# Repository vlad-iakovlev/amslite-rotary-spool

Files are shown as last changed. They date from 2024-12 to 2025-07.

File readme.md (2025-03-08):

# AMSLite Rotary Spool Holder

This project provides 3D printable rotary spool holder models, including two versions: **Bambu Style** and **Universal Version**. The rotary spool holder helps maintain filament tension during printing, reducing the likelihood of tangling and lowering the risk of print failures.

## **Features and Benefits**

1. **Easy to Print & Print Optimized**  
   The design has been optimized to reduce the need for support structures and enhance Z-axis strength. By changing the print direction, you can achieve better strength.

2. **Low Cost**  
   The universal version uses only 59g of filament, and the version with secondary claws uses only 92g of filament. The hardware costs less than 1 RMB, making it very cost-effective.

3. **Wide Filament Reel Compatibility**  
   - **Secondary Claw System**: The design includes a flexible secondary claw system that can adapt to different filament reel hole diameters, improving stability and reducing the risk of tangling. The secondary claws can be removed from the shell and assembled onto the main claws, supporting larger reels, especially those with larger hole diameters (e.g., Jayo, Sunlu brands). This modular system ensures higher stability and minimizes the chances of tangling, making it suitable for filament reels with various core diameters.
   - **Universal Version**: The design keeps the bolt diameter as small as possible (the bolt area diameter is only 40.69mm), allowing for compatibility with smaller reels, such as Sunlu 250g filament reels. The original AMSLite cannot accommodate such reels, but the universal version can. The universal version has broader compatibility, uses fewer materials, and prints faster. While it requires screwing the nut for filament reel change, it won't suffer from plastic fatigue like the elastic claw version and won't have the dropping issue that the original version may have when locking the reel in place.

4. **Replaceable Parts**  
   Except for the claw components, all other parts of the Bambu style version are replaceable as spare parts in case the original version gets damaged.

## **Required Hardware**

The rotary spool holder requires two hardware components to function properly:

1. **Torsion Spring**  
   - **Wire Diameter**: 0.8mm  
   - **Outer Diameter**: 9mm  
   - **Number of Turns**: 5  
   - **Rotation Direction**: 180° Left or Right  
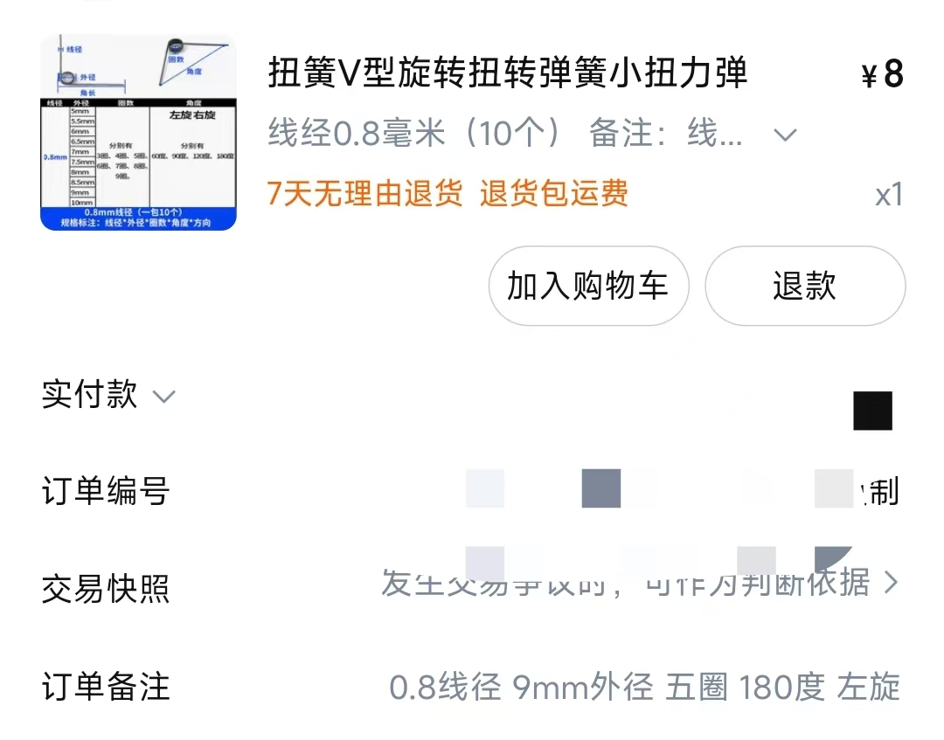
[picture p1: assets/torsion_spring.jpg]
Torsion Spring
   - 

2. **Three-Wave Gasket**  
   - **For Universal Version**  
     - **Dimensions**: 25mm x 31mm x 0.4mm  
     - **Height**: 2.9mm  
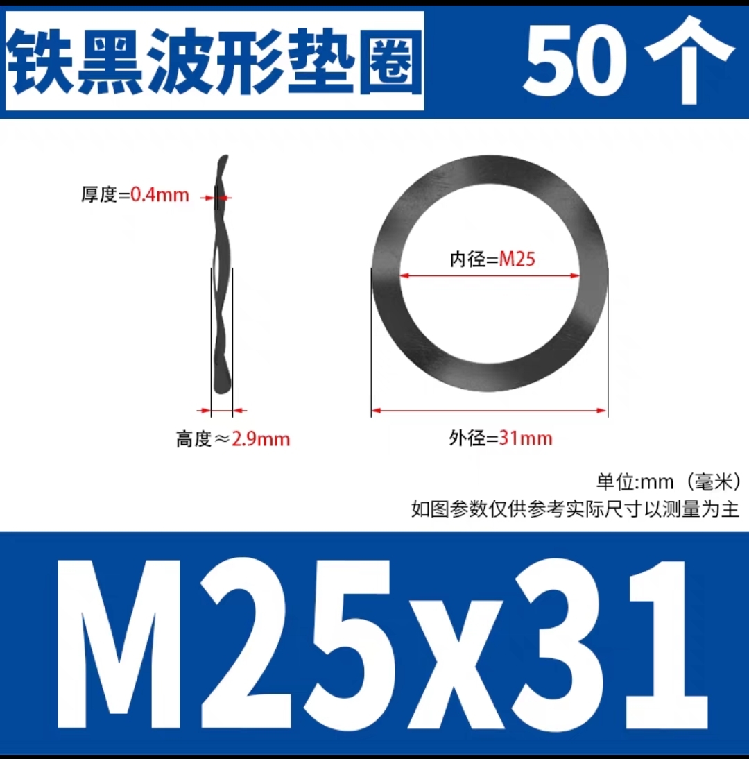
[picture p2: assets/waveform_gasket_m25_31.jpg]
Three-Wave Gasket
     - 
   - **For Bambu Style Version**  
     - **Dimensions**: 27mm x 34mm x 0.4mm  
     - **Height**: 3.1mm  
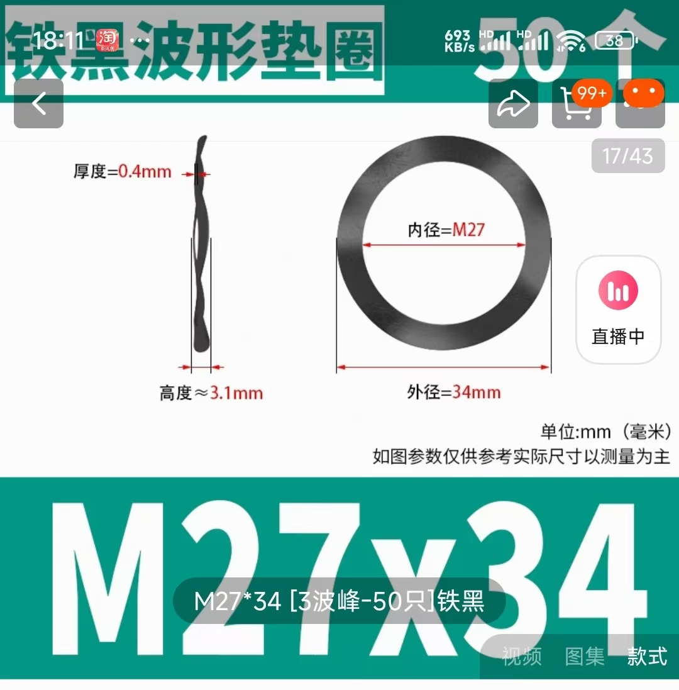
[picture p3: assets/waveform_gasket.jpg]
Three-Wave Gasket
     - 

## **Project Folder Structure**

- **assets/**: Contains snapshots, real photos, and images of hardware components.
- **3mf/**: Contains 3MF files optimized for easy printing.
- **docs/**: Usage instructions.
- **stls/**: Contains 3D model files.
  - **xxx.stl**: Integrated model.
  - **xxx_pieces/**: Split model components for easier printing.

## **3MF Files**

To simplify the printing process, 3MF files are provided. The necessary model files, orientations, and support settings have been preconfigured in the 3MF files. These files have been tested, and you can directly use them in **Orca** or **Bambu Studio**.

### [Bambu Style](./docs/bambu-style.md)
- **all-in-one.3mf**: 3MF file for the rotary spool holder (with secondary claws), all parts are placed on one plate, including both green and yellow core options (select one).
- **amslite-rotary-spool-with-secondary-claws.3mf**: 3MF file for the rotary spool holder (with secondary claws), with parts distributed across three plates. The first plate includes the base, shell, main claw seat, and main claws; the second plate includes the shaft, shaft cover, core (green and yellow, choose one), and a 1.2mm gasket; the third plate includes the secondary claw seat and secondary claws.
- **others**: Five plates: the first plate includes all 10 sizes of gaskets, the second plate includes the torsion spring bending template (including both left and right versions), the third plate includes an all-in-one main claw seat, the fourth plate includes an all-in-one core (including both yellow and green), and the fifth plate includes an all-in-one shaft.

### [Universal Version](./docs/universal-version.md)
- **universal-amslite-rotary-spool-holder-with-auto-rewind**: 3MF file for the universal rotary spool holder, including all required model files (base, shell, shaft, shaft cover, core, 1.2mm gasket, and reel nut).
- **universal-others**: Four plates: the first plate includes all 10 sizes of gaskets, the second plate includes the torsion spring bending template (including both left and right versions), the third plate includes an all-in-one core (including both yellow and green), and the fourth plate includes an all-in-one shaft.

### Other Files
- **torsion-spring-bending-template.3mf**: Includes the torsion spring bending template. The first plate is for left-hand springs, and the second plate is for right-hand springs.
- **amslite-spool-holder-cap-with-number.3mf**: Includes four numbered shaft caps (1, 2, 3, 4), useful for labeling filament reels.
- **ams-riser-v2-ams-lite-rotary-holder.3mf**: A rotary spool holder mount compatible with AMS Riser v2.
- **ams-riser-v2-ams-lite-rotary-holder-withAMS.3mf**: A rotary spool holder mount compatible with AMS Riser v2, printed separately with different colors for the yellow and green slots.
- **debug-xxx.3mf**: Includes a hollowed-out cover and four different gasket sizes for debugging. Refer to the [debug-guide](./docs/debug-guide.md) for related documentation.

## **License**

This project is licensed under the [Creative Commons Attribution 4.0 International License](https://creativecommons.org/licenses/by/4.0/), feel free to modify and distribute with proper attribution.

## **Disclaimer**

Please note that the rotary spool holder and secondary claw system design is not intended for high-load applications or professional tool use. It is suitable for everyday 3D printing filament management.

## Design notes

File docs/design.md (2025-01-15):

# AMS Lite Rotary Spool Design Document

This document provides a detailed overview of the design process for the AMS Lite Rotary Spool, including the creation and assembly steps of each component to ensure optimal functionality and performance.

## Table of Contents

- [Introduction](#Introduction)
- [Design Process](#Design-Process)
- [Design Challenges and Solutions](#Design-Challenges-and-Solutions)
- [Conclusion](#Conclusion)

## Introduction

The AMS Lite Rotary Spool is a versatile spool designed to meet the needs of 3D printing applications. It supports various types and sizes of filaments while ensuring ease of printing and low production cost.

## Design Process

The design of the Rotary Spool focuses on the precise matching and fitting of each part, ensuring that all components are easy to print, have good strength, and can support filaments of different diameters.

### 1. **Core Components (Green and Yellow Versions)**

*The core components are derived from measurements of the original version and can serve as replacements for the original spool parts*. The core is the central part of the rotary spool, and the design considers the direction of rotation. The green and yellow versions provide different options to meet the user's needs for different filament feeding directions.

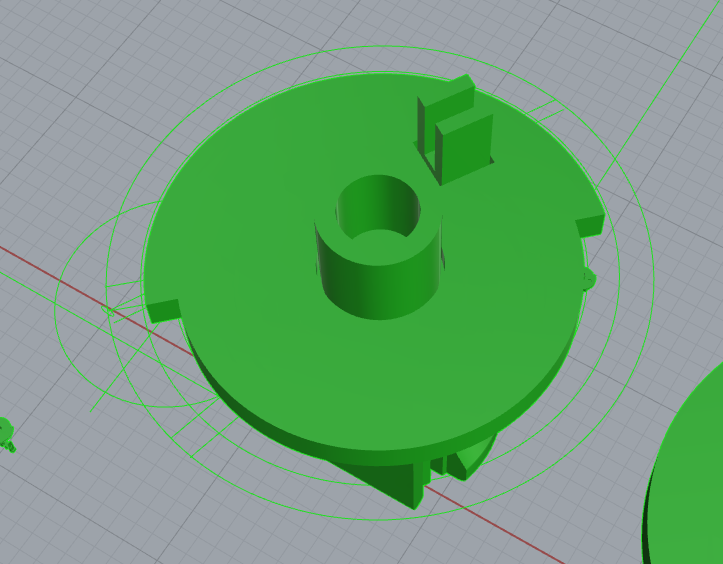
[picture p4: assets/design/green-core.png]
Green Core Design Guidelines

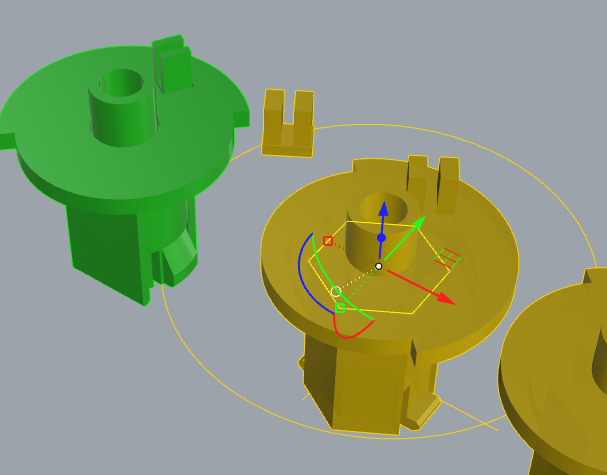
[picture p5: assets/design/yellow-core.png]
Yellow Core Design Guidelines


To enhance the strength along the Z-axis and facilitate printing, the core components are designed in separate pieces.

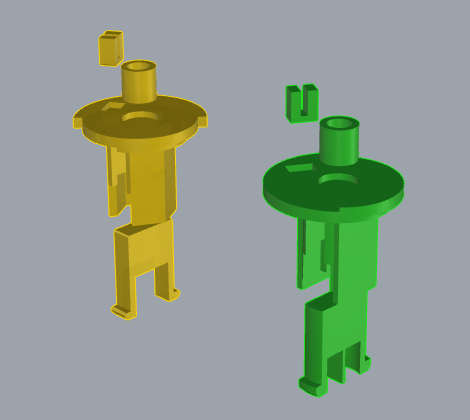
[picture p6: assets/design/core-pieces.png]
Core Components Disassembly Design


### 2. **Shaft Design**

*The shaft is based on measurements of the original version and can serve as a replacement part*. The shaft connects the core to the base and outer shell, ensuring smooth rotation.

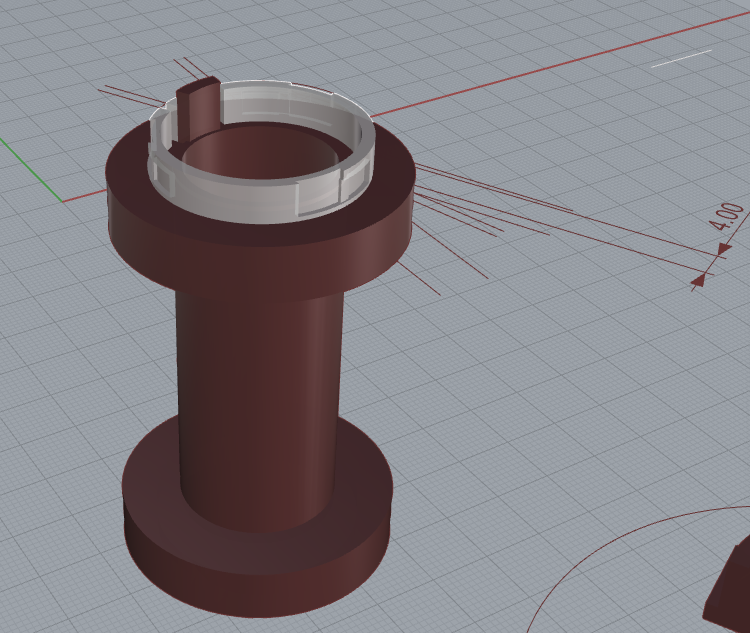
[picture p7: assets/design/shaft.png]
Shaft Design Guidelines


To address the Z-axis strength issue and improve printing convenience, the shaft is also split into multiple pieces.

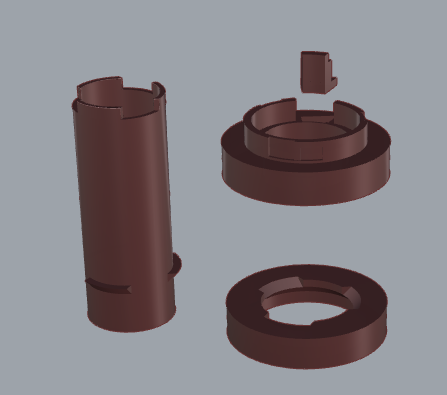
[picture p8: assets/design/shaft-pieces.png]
Shaft Design Disassembly


### 3. **Shaft Cover Design**

*The shaft cover is derived from measurements of the original version and can serve as a replacement part*.

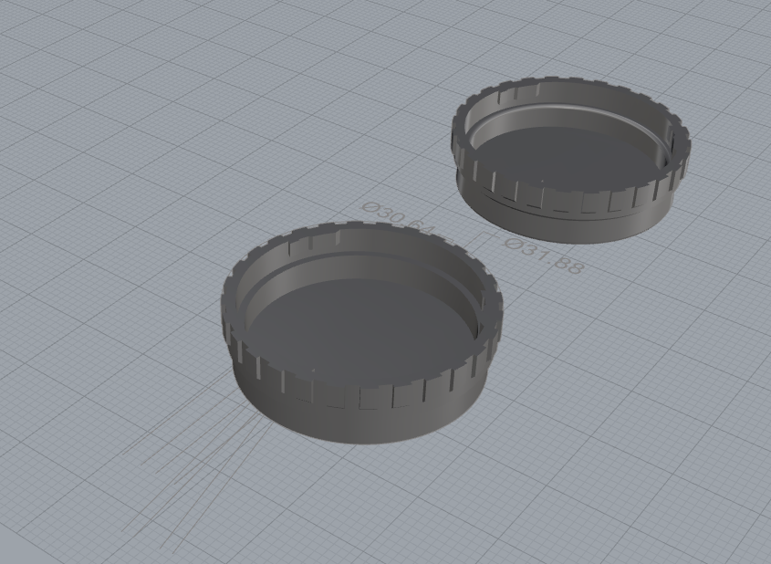
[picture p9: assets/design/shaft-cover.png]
Shaft Cover Design Guidelines


### 4. **Base Design**

*The base is based on measurements of the original version and can serve as a replacement part*. Since the original metal spring clips do not have a universal solution, we have used three-wave gaskets. As a result, the base model differs slightly from the original version. To achieve the correct friction, different gasket thicknesses are provided for the user's adjustment.

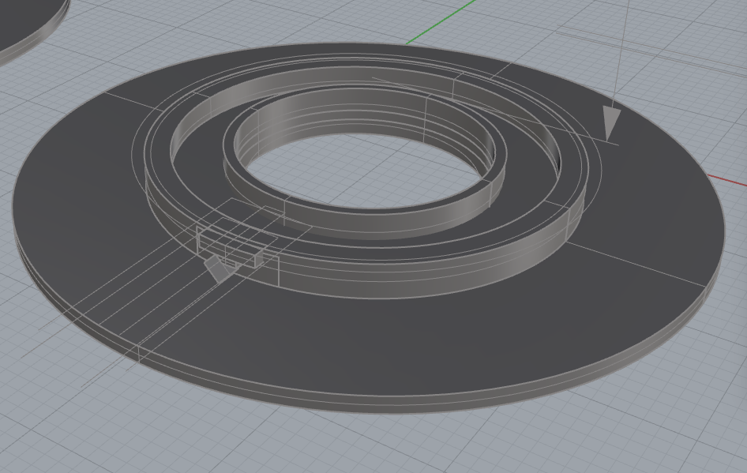
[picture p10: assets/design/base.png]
Base Design Guidelines


If the suitable pressure is uncertain, users can print and test different gasket thicknesses. For example, printing 0.2mm, 0.4mm, and 0.8mm gaskets will allow combinations that result in seven different thicknesses (0.2mm, 0.4mm, 0.6mm, 0.8mm, 1.0mm, 1.2mm, 1.4mm).

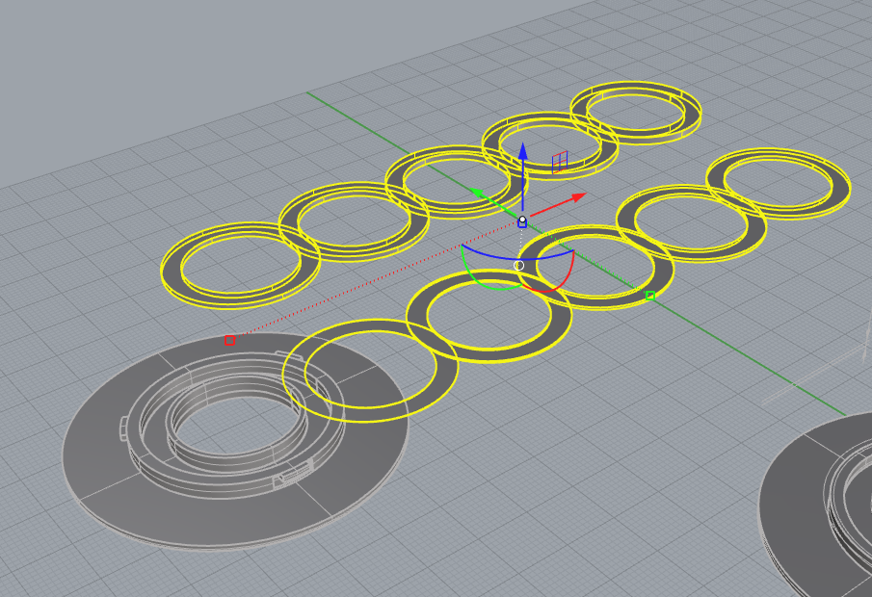
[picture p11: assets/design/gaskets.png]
Different Thickness Gaskets for Pressure Adjustment


### 5. **Main Claw Seat Design**

*The main claw seat is derived from measurements of the original version and can serve as a replacement part*. The original version uses C-type spring clips, but there is no universal solution, so we adopted a Z-spring design for the claws. To ensure a secure connection between the claw and the claw seat, M1.6 threaded holes for screws have been added.

To enhance the strength along the Z-axis, the claw seat panel has been thickened, and the clip portions have been split into separate pieces for improved strength.

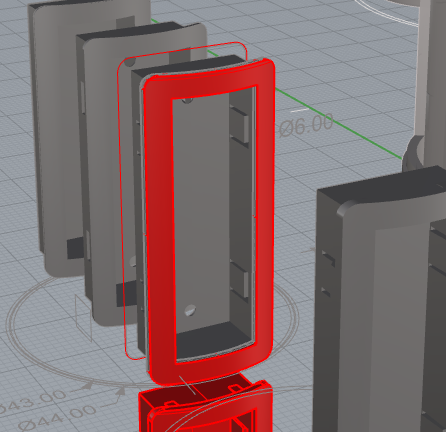
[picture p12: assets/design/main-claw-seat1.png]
Main Claw Seat Design

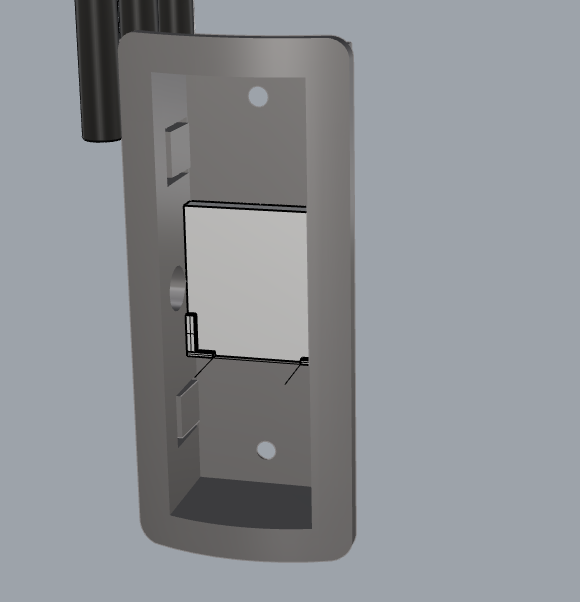
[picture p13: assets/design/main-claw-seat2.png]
Main Claw Seat Design

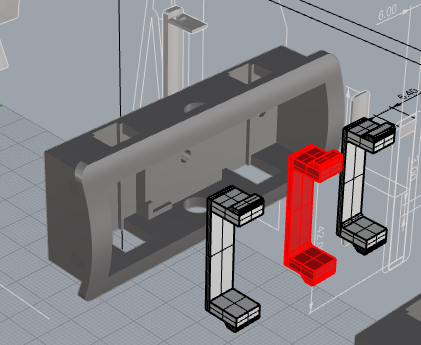
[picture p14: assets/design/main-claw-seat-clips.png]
Main Claw Seat Clips Disassembly Design


### 6. **Main Claw Design**

The main claw’s shape was derived from measurements of the original version, ensuring the upper part rests on the edge of the outer shell, with the lower part’s distance from the shell being verified through measurements. The original version caused the tail end of the claw to rub against the base, so the model's tail end length was reduced accordingly.

To achieve similar deformation properties as the original version, a Z-spring structure was used, with the connection point located along a circular rotational path that aligns with the inner edge of the claw seat.

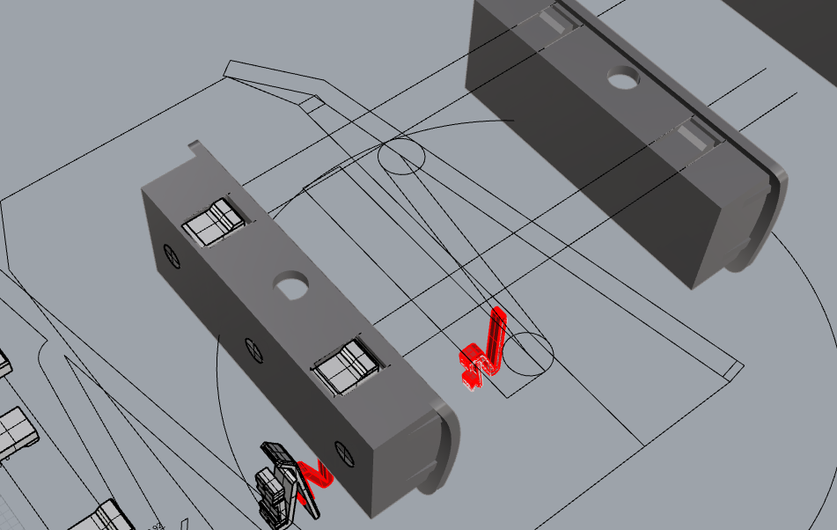
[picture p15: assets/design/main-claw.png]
Main Claw Design


Additionally, to support the secondary claw system, two square slots were added to the main claw based on the principle of hole boards.

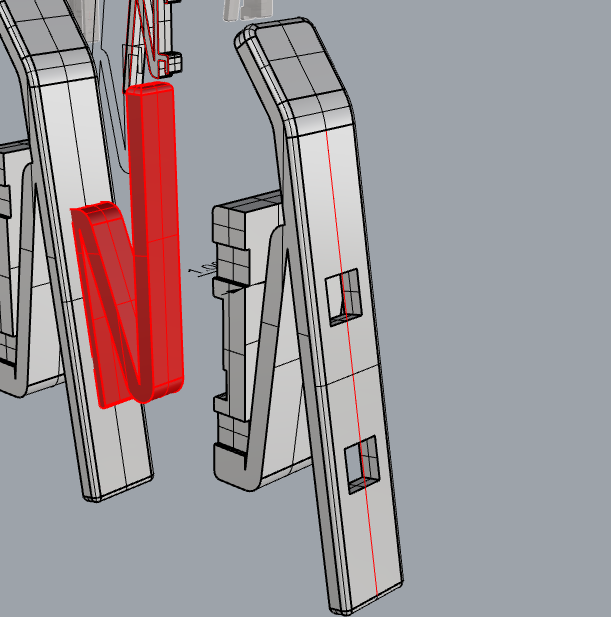
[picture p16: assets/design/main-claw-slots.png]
Main Claw Slots


### 7. **Secondary Claw and Secondary Claw Seat Design**

The secondary claw is designed to support larger diameter filament spools, requiring quick disassembly and supporting two configurations. The secondary claw uses a Z-spring structure, and its connection point is similar to the main claw, aligned with the inner edge of the claw seat through a rotational path.

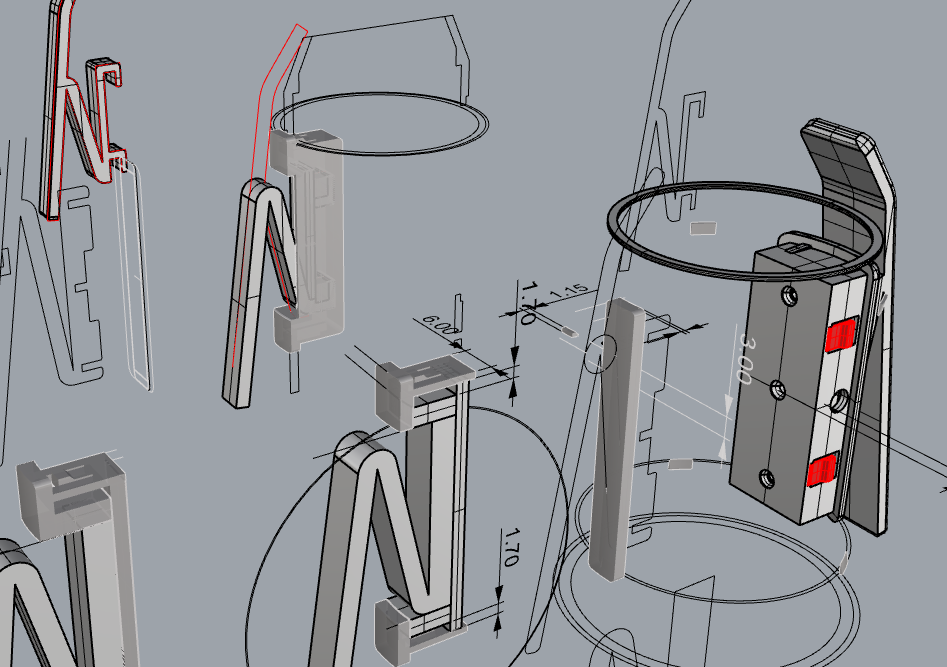
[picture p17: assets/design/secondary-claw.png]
Secondary Claw Design


The secondary claw seat design follows the principle of hole boards, using a hook-and-snap design for quick disassembly. To enhance the strength of the connection between the secondary claw seat and the outer shell, a supporting backplate was added to address instability caused by deformation.

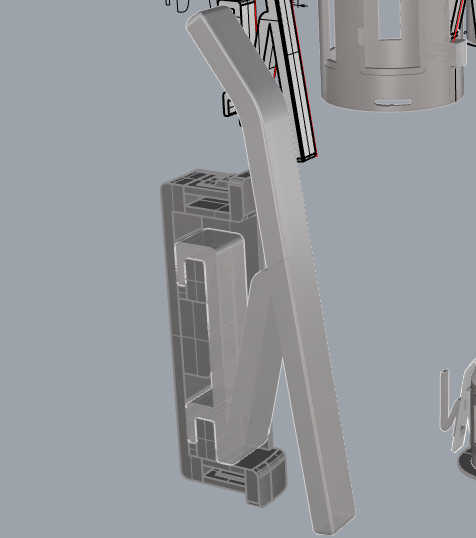
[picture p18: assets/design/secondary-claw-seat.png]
Secondary Claw Seat Design

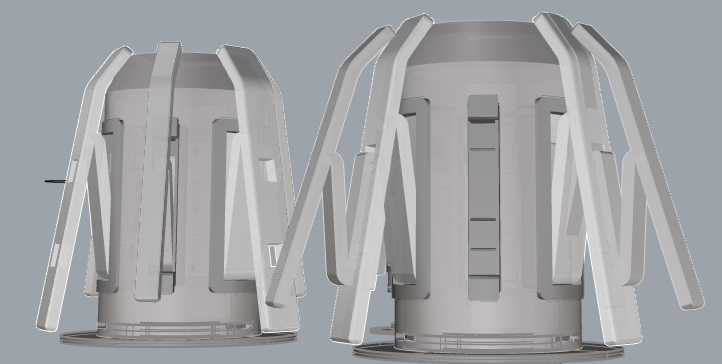
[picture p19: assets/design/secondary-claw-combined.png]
Secondary Claw Combined Configuration


## Design Challenges and Solutions

### Challenge 1: Ensuring Print Strength
Due to the nature of 3D printing, the strength along the Z-axis is significantly lower than along the XY axes. To ensure the rotary spool has high strength, we used part disassembly and optimized the print direction to improve Z-axis strength.

### Challenge 2: Supporting Filaments of Different Sizes
To accommodate different filament diameters, we designed the secondary claw system. The secondary claw can be printed as needed and, when in use, can be quickly detached from the outer shell and reassembled onto the main claw to ensure the rotary spool can adapt to different filament sizes.

## Conclusion

The design goal of the AMS Lite Rotary Spool is to make it easy for users to print, support multiple filament sizes, and deliver excellent performance. By optimizing the design and material selection, we created a cost-effective and durable rotary spool system that meets the needs of most 3D printing applications.

---

For any questions or feedback, please feel free to ask in the [Issue](https://github.com/zjoycelee/amslite-rotary-spool/issues).

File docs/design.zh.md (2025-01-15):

# AMS Lite 回转轴设计文档

本文档详细介绍了AMS Lite回转轴的设计过程，包括每个部件的创作和组装步骤，以确保最佳的功能性和性能。

## 目录

- [简介](#简介)
- [设计过程](#设计过程)
- [设计挑战与解决方案](#设计挑战与解决方案)
- [总结](#总结)

## 简介

AMS Lite回转轴是为了满足3D打印应用需求而设计的多功能回转轴。它支持多种类型和规格的耗材，同时确保易于打印，并具备较低的生产成本。

## 设计过程

该回转轴的设计注重每个部件的精准匹配和配合，确保所有零件易于打印且可以保持较好的强度，并能支持不同直径的耗材。

### 1. **核心部件（绿色与黄色版本）**
*通过测绘原版获得，可用作原版替换件*，核心部件是回转轴的核心，设计时考虑了旋转方向。绿色和黄色版本提供了不同选择，满足用户不同进料方向的需求。

绿色核心设计辅助线
黄色核心设计辅助线

为了增强Z轴方向的强度并便于打印，核心部分进行了拆件设计。

核心部分拆件设计

### 2. **中轴设计**
*通过测绘原版获得，可用作原版替换件*，中轴连接核心与底座、外壳，确保旋转的流畅性。

中轴设计辅助线

考虑到Z轴方向的强度问题，并为了方便打印，中轴部分也进行了拆件设计。

中轴设计拆件

### 3. **轴盖设计**
*通过测绘原版获得，可用作原版替换件*。

轴盖设计辅助线

### 4. **底座设计**
*通过测绘原版获得，可用作原版替换件*。由于原版金属弹片没有通用方案，我们使用了三波峰垫片。因此，底座模型与原版有些许不同。为了获得合适的摩擦力，提供了不同厚度的垫片，方便用户调节。

底座设计辅助线

如果不确定合适的压力，可以打印不同厚度的垫片进行组合测试。例如，可以打印0.2、0.4、0.8mm三个厚度的垫片，并通过组合测试，获得7种不同的厚度(0.2mm, 0.4mm, 0.6mm, 0.8mm, 1.0mm, 1.2mm, 1.4mm)。

不同厚度的压力调节垫片

### 5. **主爪座设计**
*通过测绘原版获得，可用作原版替换件*，由于原版爪子使用C型弹片，但没有通用方案，因此采用了Z字形弹簧结构的爪。为了确保爪与爪座的稳固连接，增加了M1.6沉孔螺丝的孔洞。

为了增加Z轴方向的强度，爪座的面板进行了加厚，并且对卡扣部分进行了拆件设计。

主爪座设计

主爪座设计

主爪座卡扣拆件设计

### 6. **主爪设计**
主爪的外形是通过测绘原版获得的，确保上端能够搭在外壳边缘，下端距离外壳的长度也已通过测量确认。原版按压时，尾端会擦到底座，因此对模型尾端长度做了一定缩减。

为了让主爪具有类似原版的形变能力，采用了Z字形弹簧结构，连接位置通过旋转的圆形路径与爪座的内边缘进行配合。

主爪设计

此外，为了支持副爪系统，参考了洞洞板的原理，在主爪上增加了两个方形槽位。

主爪孔洞

### 7. **副爪与副爪座设计**
副爪设计用于支持更大直径的耗材卷，要求能够快速拆卸并支持两种形态。副爪采用Z字形弹簧结构，与主爪的连接位置类似，通过旋转的路径与爪座的内边缘对接。

副爪设计

副爪座的设计借鉴了洞洞板原理，挂钩式卡扣设计使得副爪能够快速拆卸。为了增强副爪座与外壳的连接强度，副爪座的背面增加了支撑板，以解决形变引起的连接不稳固问题。

副爪座设计

副爪组合形态

## 设计挑战与解决方案

### 挑战 1：确保打印强度
由于3D打印特性，Z轴方向的承受力远低于XY方向。为了确保回转轴具备高强度，我们通过拆件设计并优化打印方向，从而提升了Z轴方向的强度。

### 挑战 2：支持不同规格的耗材
为了解决支持不同直径耗材的问题，我们设计了副爪系统。副爪可以根据需求进行打印，并在使用时根据耗材的直径从外壳上快速拆卸并装配到主爪上，确保回转轴能够适应不同尺寸的耗材。

## 总结

AMS Lite回转轴的设计目标是便于用户打印、支持多种规格的耗材，并提供优异的性能。通过优化设计和材料选择，创造了一个成本、耐用的回转轴系统，能够满足大多数3D打印应用的需求。

---

如有任何问题或反馈，欢迎在[Issue](https://github.com/zjoycelee/amslite-rotary-spool/issues)中提问。

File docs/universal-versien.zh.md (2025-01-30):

# AMSLite 通用回转轴

本项目提供了一个适用于3D打印机的回转轴模型。回转轴能够在打印过程中保持线材的张力，减少线材缠绕的可能性，从而降低打印失败的风险。此模型与拓竹原版回转轴相同的核心，并可使用 AMSLite 固定轴（18mm 直径）。

## 特点与优势

1. **易于打印 & 打印优化**  
   该设计经过优化，拆件使得便于打印，减少了对支撑结构的需求，同时强化了 Z 轴方向的强度。改变打印方向可以获得更好的强度。

2. **料盘适用广**  
   螺杆部分直径为 40.69mm，螺母部分最大直径为 80mm，螺杆长度为 75mm，适配绝大多数 200g、250g 和 1kg 的料盘。

3. **低成本**  
   该设计非常具有成本效益，仅需 59 克耗材，硬件成本不到 1 元人民币，经济实惠。

4. **打印速度快**  
   完成打印时间仅需约 2.5 小时。

5. **原版固定轴可用**  
   核心部分提供黄色和绿色两个版本，内径与原版一致，模型高度与原版相同，因此原版固定轴可与此模型兼容。

## 预览 - 通用回转轴

- **着色图预览**  
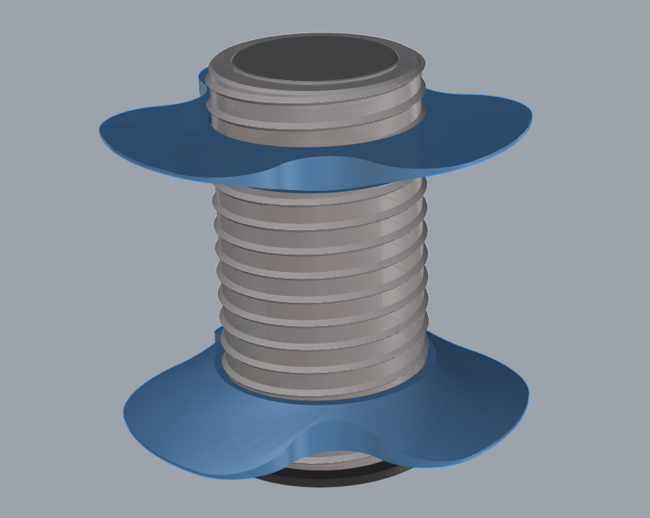
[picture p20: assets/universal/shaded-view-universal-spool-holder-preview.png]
预览
  

- **分体图**  
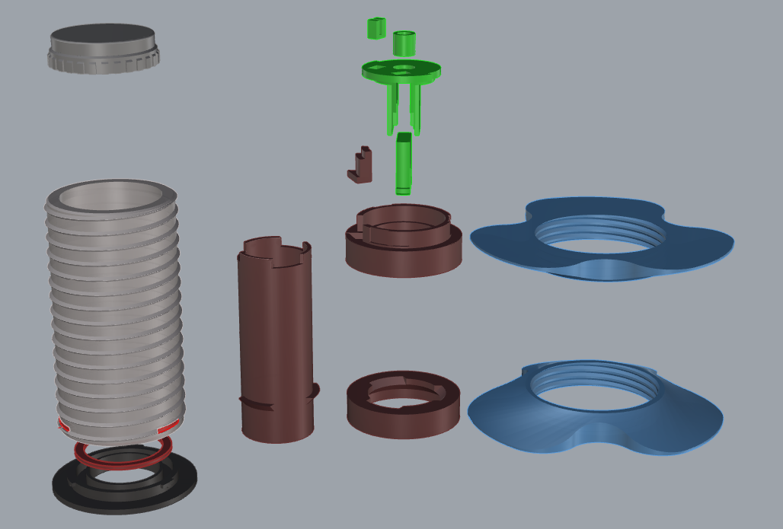
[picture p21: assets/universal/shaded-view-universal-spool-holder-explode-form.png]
回转轴的分体图
  

- **实拍图**  
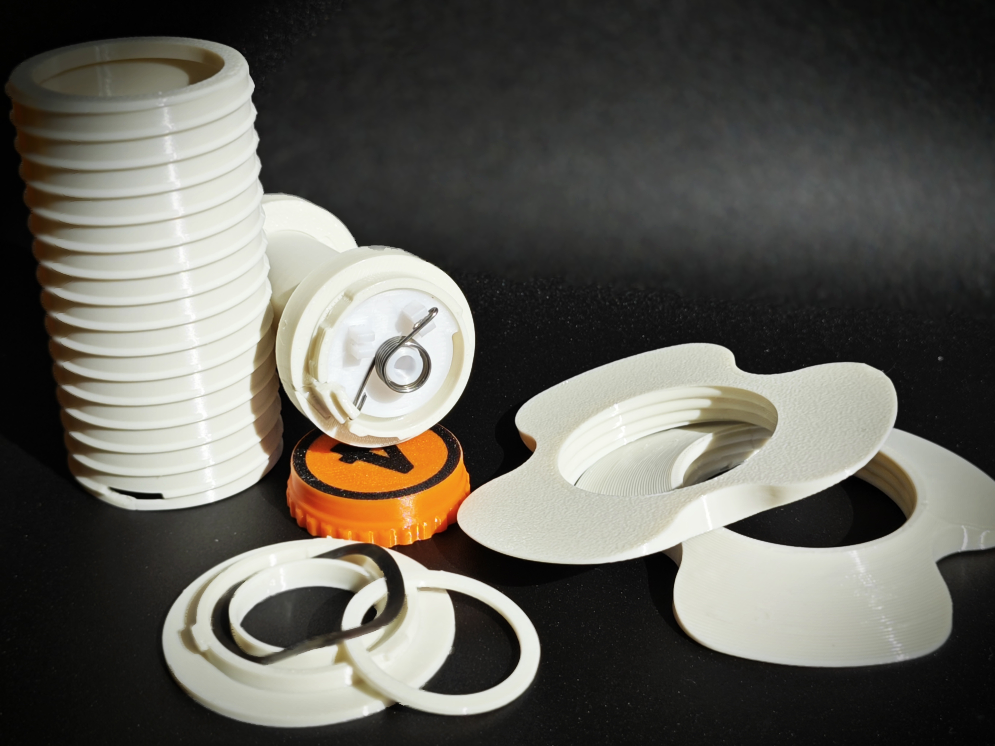
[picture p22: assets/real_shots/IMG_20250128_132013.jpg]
实拍图 - 散件
  
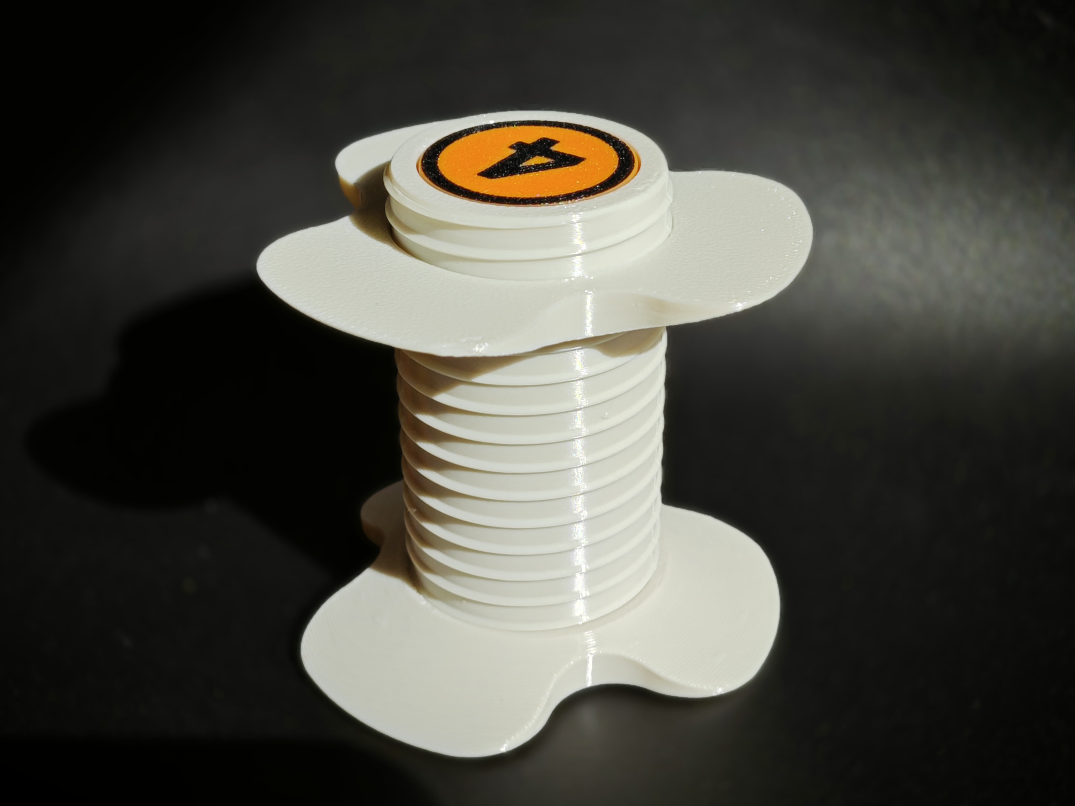
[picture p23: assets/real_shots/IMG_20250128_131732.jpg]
实拍图
  
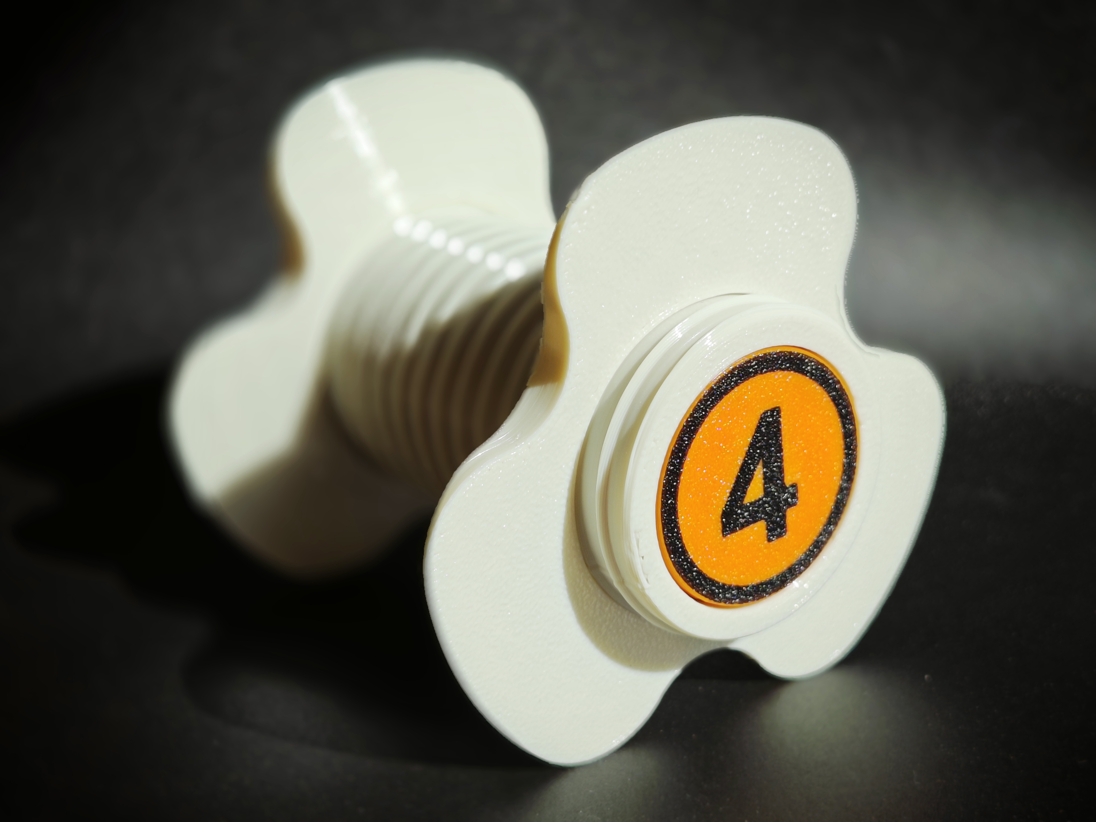
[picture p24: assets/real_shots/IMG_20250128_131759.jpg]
实拍图 - 顶端
  
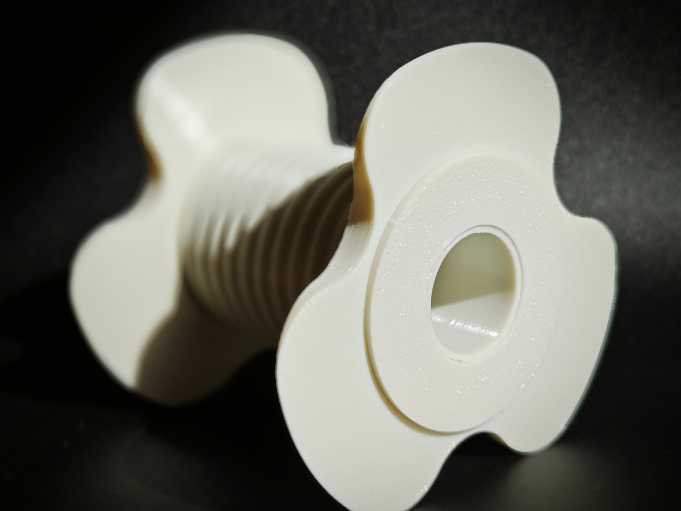
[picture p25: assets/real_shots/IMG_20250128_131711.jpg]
实拍图 - 底端
  

## 动态展示

动态展示

## 所需硬件

此模型需要以下两个硬件组件才能正常工作：

1. **三波形垫片**  
   - **尺寸**: 25mm x 31mm x 0.4mm  
   - **高度**: 2.9mm  
   - 三波形垫片

2. **扭簧**  
   - **线径**: 0.8mm  
   - **外径**: 9mm  
   - **旋转方向**: 180° 左旋/右旋  
   - **圈数**: 5  
   - 扭簧

## 3MF 文件

为简化打印过程，提供了3MF文件，您可以直接在 **Orca** 或 **Bambu Studio** 中使用：

- **universal-amslite-rotary-spool-holder-with-auto-rewind**: 包含通用回转轴的3MF文件，涵盖所有所需模型文件：底座、外壳、中轴、轴盖、核心（黄色和绿色，选择其一）、1.2mm 垫片、料盘螺母。
- **universal-others**: 包括四盘文件：
  1. 第一盘：所有 10 种规格的垫片。
  2. 第二盘：扭簧弯曲模板（左右版本）。
  3. 第三盘：一体打印的核心（包括黄色和绿色版本）。
  4. 第四盘：一体打印的中轴。

在 **Orca** 或 **Bambu Studio** 中打开这些3MF文件，即可开始打印！

## 组装说明

1. **主组件组装**  
   打印以下文件：**base_d46.stl**、**shaft_cover.stl** 和 **shell_with_support.stl**/**shell.stl**。这些是回转轴的基础部件。  
   **推荐**：建议打印 **shell_with_support.stl**，该模型在悬空孔洞部位增加了支撑，打印完成后可手动去除，能够获得更好的锁定孔。

2. **核心部件**  
   - 若希望打印一体化的核心部件，使用 **green_version.stl**（绿色版本）或 **yellow_version.stl**（黄色版本）。
   - 若希望将核心部件分开打印并用胶水组装，请打印 **green_version_pieces/** 和 **common_pieces/**（绿色版本），或 **yellow_version_pieces/** 和 **common_pieces/**（黄色版本）。分体打印有助于减少支撑材料并优化强度。
   - **common_pieces/** 文件夹包含核心部件所需的共享部件，例如扭簧中心和短端卡扣。

3. **压力垫圈**  
   根据您的组装需求，从 **gaskets/** 文件夹中选择适合的垫圈厚度。

4. **中轴组件**  
   - **一体化版本**：使用 **shaft.stl** 打印完整中轴模型作为单一部件。
   - **分体打印版本**：若希望将中轴分开打印并用胶水组装，请打印 **shaft_pieces/**。

## 许可

本项目采用 [Creative Commons Attribution 4.0 International License](https://creativecommons.org/licenses/by/4.0/)，欢迎修改和分发，但请注明出处。

## 免责声明

请注意，回转轴和副爪系统设计并不适用于承受极高负载或作为专业工具使用，仅适用于日常 3D 打印相关的线材管理。

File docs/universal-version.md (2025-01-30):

# AMSLite Universal Rotary Spool Holder

This project provides a printable rotary spool holder model for 3D printers. The rotary spool holder helps maintain tension on the filament during printing, reducing the chance of tangling and thereby lowering the risk of print failures. The model is compatible with the AMSLite fixed axle (18mm diameter) and uses the same core as the original Bambu design.

## Features & Advantages

1. **Easy to Print & Print Optimized**  
   This design is optimized for easy printing, reducing the need for support structures. It also enhances the Z-axis strength by splitting parts, and changing the print orientation provides better strength.

2. **Wide Spool Compatibility**  
   The screw section has a minimal diameter of 40.69mm, and the nut section can accommodate spools up to 80mm in diameter. The screw length is 75mm, making it compatible with most 200g, 250g, and 1kg filament spools.

3. **Low Cost**  
   This design is cost-effective, requiring only 59g of filament, with hardware costs under 1 RMB, making it very affordable.

4. **Fast Print Time**  
   The print time is approximately 2.5 hours.

5. **Compatible with Original Fixed Axle**  
   The core part comes in yellow and green versions, and the inner diameter of the shaft is the same as the original. The model height matches the original, so any fixed axle used with the original design will work with this model and can be installed on the AMSLite.

## Preview - Universal Rotary Spool Holder

- **Shaded View Preview**  
  Preview

- **Exploded View**  
  Exploded View of Rotary Spool Holder

- **Real Shots**  
  Real Shot - Parts
  Real Shot
  Real Shot - Top
  Real Shot - Bottom

## Dynamic Preview

Dynamic Preview

## Required Hardware

This model requires the following hardware components to function properly:

1. **Three-Wave Gasket**  
   - **Size**: 25mm x 31mm x 0.4mm  
   - **Height**: 2.9mm  
   - Three-Wave Gasket

2. **Torsion Spring**  
   - **Wire Diameter**: 0.8mm  
   - **Outer Diameter**: 9mm  
   - **Rotation Direction**: 180° Left/Right Rotation  
   - **Turns**: 5  
   - Torsion Spring

## 3MF Files

To simplify the printing process, 3MF files are provided. You can directly use them in **Orca** or **Bambu Studio**:

- **universal-amslite-rotary-spool-holder-with-auto-rewind**: Contains the 3MF file for the universal rotary spool holder, including all required models: base, shell, shaft, shaft cover, core (yellow and green, choose one), 1.2mm gasket, and spool nut.
- **universal-others**: Includes four disks:
  1. The first disk contains all 10 different gasket specifications.
  2. The second disk contains the torsion spring bending template (left and right versions).
  3. The third disk contains the integrated core (yellow and green versions).
  4. The fourth disk contains the integrated shaft.

Simply open these 3MF files in **Orca** or **Bambu Studio** to start printing!

## Assembly Instructions

1. **Assembling the Main Components**  
   Print the following files: **base_d46.stl**, **shaft_cover.stl**, and **shell_with_support.stl**/**shell.stl**. These are the base components of the rotary spool holder.  
   **Recommended**: Print **shell_with_support.stl**, as this model adds supports to the holes in the suspension areas, which can be manually removed after printing for better locking holes.

2. **Core Components**  
   - If you wish to print the core as a single part, use **green_version.stl** (green version) or **yellow_version.stl** (yellow version).
   - If you want to print the core components separately and assemble them with glue, print **green_version_pieces/** and **common_pieces/** (green version), or **yellow_version_pieces/** and **common_pieces/** (yellow version). Separately printed parts help reduce support material and optimize strength.
   - The **common_pieces/** folder contains shared parts required for both versions of the core, such as the torsion spring center and short end clips.

3. **Gaskets**  
   Choose the appropriate gasket thickness from the **gaskets/** folder based on your assembly needs.

4. **Shaft Assembly**  
   - **Integrated Version**: Use **shaft.stl** to print the complete shaft model as a single part.
   - **Separate Printing Version**: If you wish to print the shaft separately and assemble it with glue, print **shaft_pieces/**.

## License

This project is licensed under the [Creative Commons Attribution 4.0 International License](https://creativecommons.org/licenses/by/4.0/), which allows for modification and distribution with proper attribution.

## Disclaimer

Please note that the rotary spool holder and secondary claw system are not designed for high load-bearing or professional tool use. They are intended for general 3D printing filament management only.

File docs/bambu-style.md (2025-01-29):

# AMS Lite Rotary Spool with Secondary Claws

This project provides a 3D printable rotary spool with an optional secondary claw setup for 3D printers. The rotary spool helps in maintaining the filament tension during printing, reducing the likelihood of tangled filament and print failure.

## Features & Advantages

1. **Easy to Print & Print Optimized**: The design is optimized for easy printing, the split makes it easy to print, reduces the need for the support structure, and the part that needs to be strengthened in the Z-axis direction is splited, and the printing direction can be changed to obtain better strength.
2. **Secondary Claw System**: The design includes a flexible secondary claw system that can be easily adapted to support filament rolls with varying core hole diameters, improving stability and reducing the risk of tangling. The secondary claws can be detached from the shell and assembled onto the main claw, allowing the spool to accommodate larger filament rolls with wider center holes (such as those from Jayo). This modular system ensures greater stability and minimizes the likelihood of filament tangling, making it versatile for different spool sizes.
3. **Cost-Effective**: The design is cost-efficient, requiring only 92g of filament material. The hardware cost is less than 1 RMB, making it an affordable option.
4. **Replaceable Parts**: Except for the claws, all other parts of the model are designed to replace the original versions, providing flexibility for upgrades and customization.

## Preview - Rotary Spool with Secondary Claws

Here are some shaded view images of the rotary spool with secondary claws:

- **Original and Combined Form**
  
  Shaded View of Original and Combined Form

- **Exploded Assembly View**
  
  Exploded Assembly View of Rotary Spool

- **Real Shots**
  
  Real Shot - original view
  Real Shot - assembly view
  Real Shot - top
  Real Shot - bottom

### Demonstration GIF

### Supports Standard Size Spool Center Hole  
The original form of the Ratory Spool (with secondary claws mounted on the shell), suitable for most filament brands, such as Bambu, Tinmorry, etc.  
Dynamic Display - Origin

### Supports Large Size Spool Center Hole  
The combined form of the Ratory Spool (with secondary claws mounted on the main claws), suitable for large-center-hole filament brands, such as Jayo, etc.  
Dynamic Display - Combined

## Required Hardware

This model requires two hardware components to function properly:

1. **Three-Wave Gasket**  
   - **Dimensions**: 27mm x 34mm x 0.4mm
   - **Height**: 3.1mm  
   - Three-Wave Gasket

2. **Torsion Spring**  
   - **Wire Diameter**: 0.8mm  
   - **Outer Diameter**: 9mm  
   - **Number of Turns**: 5  
   - **Rotation**: 180-degree left-hand/right-hand twist  
   - Torsion Spring

## 3MF Files

To make printing easier, 3MF files have been provided for direct use with **Orca** or **Bambu Studio**:

- **all-in-one.3mf**: 3MF file for the ratory spool(include secondary claws), all in one plate, include both green and yellow core, you should uncheck one according to yourself.
- **amslite-rotary-spool-with-secondary-claws.3mf**: 3MF file for the ratory spool(include secondary claws), divide into 3 plates, first one include main claw seats, main claws, base, shell; second one include core(both green and yellow, you should uncheck one according to yourself), shaft, cover, 1.2mm gasket; third one include secondary claw seats and secondary claws
- - **others**: Five plates: the first includes all 10 sizes of gaskets, the second includes torsion spring bending templates (both left and right versions), the third is the integrated main claw seat, the fourth is the integrated core (green and yellow), and the fifth is the integrated shaft.

Simply open the 3MF files in **Orca** or **Bambu Studio**, and you'll be ready to print!

## Assembly Instructions

1. **Main Assembly**:
   - First, print the **base.stl**, **shaft_cover.stl**, and **shell_with_secondary-claws(thickened).stl** files. These parts are the foundation of the rotary spool. 
   - **Recommendation**: It is recommended to print **shell_with_secondary-claws(thickened).stl** because it includes all the functionality of **shell(thickened).stl**. If you wish to add the secondary claw system later, based on this shell, you only need to add the secondary claw seats and claws. If you don’t need the secondary claw system, simply use **shell_with_secondary-claws(thickened).stl** without the additional parts.

2. **Claw Assembly**:
   - The **basic.stl** is designed for the standard rotary spool and does not have the necessary slots for secondary claws. It should not be used if you want to add the secondary claw system.
   - The **main claws** should be printed using **main_claw_with_secondary_slots.stl** if you plan to use the secondary claws to support larger filament rolls with bigger center holes. This main claw has slots that can accommodate **secondary_claw.stl**.
   - The **secondary_claw.stl** can only be combined with **main_claw_with_secondary_slots.stl** or **secondary_claw_seat.stl**. These parts include the necessary slots to fit the secondary claws.
   - **Recommendation**: It is recommended to print **main_claw_with_secondary_slots.stl** because it includes all the functionality of **basic.stl**. If you wish to add the secondary claw system later, based on this claw, you don't need to reprint the main claw. If you don’t need the secondary claw system, simply use **main_claw_with_secondary_slots.stl** without the additional parts.

3. **Claw Seats**:
   - The main and secondary claw seats are printed using **main_claw_seat.stl** and **secondary_claw_seat.stl**, respectively.

4. **Core Parts**:
   - If you prefer to print the core as a single piece, use **green_version.stl** for the green version or **yellow_version.stl** for the yellow version.
   - If you prefer to print the core in separate parts and assemble them with glue, use the following, the advantage of printing separately is reduced support material and optimized strength.:
     - For the green version, print the parts from **green_version_pieces/** and **common_pieces/**.
     - For the yellow version, print the parts from **yellow_version_pieces/** and **common_pieces/**.
   - The **common_pieces/** folder contains parts that should be printed regardless of which version you choose (green or yellow), such as the torsion spring center and short-end clip.

5. **Pressure Gaskets**:
   - Select a suitable gasket thickness based on your assembly's needs, from **pressure_gaskets/**. 

6. **Shaft**:
   - The shaft assembly has two versions:
     - **One-piece version**: **shaft.stl** is the complete model for the shaft, which can be printed as a single piece.
     - **Separate pieces version**: If you prefer to print the shaft in parts and assemble them with glue, print the parts from the **shaft_pieces/** folder. The advantage of printing separately is reduced support material and optimized strength.

7. **Torsion Spring Bending**:
   - If you need to bend the torsion spring, use the **torsion_spring_bending_template_left.stl** or **torsion_spring_bending_template_right.stl** from the **torsion_spring_bending_template/** folder.

## Licensing

This project is licensed under the [Creative Commons Attribution 4.0 International License](https://creativecommons.org/licenses/by/4.0/).

## Notes

- Ensure you check the correct version (green or yellow) of the core parts for compatibility with your other components.
- The assembly may require a few additional tools such as screws or clips, which are not included in the 3D model files but are commonly available.

## Conclusion

The AMS Lite Rotary Spool with Secondary Claws provides an easy-to-print solution for managing filament spools, reducing print failures, and accommodating larger filament rolls.

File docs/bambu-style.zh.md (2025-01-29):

# AMSLite回转轴（带副爪系统）

这个项目提供了一个可打印的回转轴模型，该模型包含一个可选的副爪系统，适用于3D打印机。回转轴有助于保持打印过程中的线材张力，减少线材缠绕的可能性，从而降低打印失败的风险。
该模型外观与拓竹类似，除了爪部件外，模型的其他部件均可替换拓竹原版。

## 特点与优势

1. **易于打印 & 打印优化**: 该设计经过优化，拆件使得便于打印，减少了对支撑结构的需求，以及Z轴方向强度需要强化的部分做了拆件处理, 改变打印方向可以获得更好的强度。
2. **副爪系统**: 设计包括一个灵活的副爪系统，可根据不同的耗材轴心孔径进行适配，提高稳定性并减少缠线的风险。副爪可以从外壳上拆下并组装到主爪上，使得回转轴能够支持直径更大的料盘，尤其适用于孔径较大的料盘（例如Jayo,Sunlu品牌）。这种模块化系统确保了更高的稳定性，并最大限度地减少了缠线的可能性，适用于不同尺寸的耗材轴心。
3. **低成本**: 该设计非常具有成本效益，仅需92克耗材，硬件成本不到1元人民币，十分经济实惠。
4. **可替换部件**: 除了爪部件外，模型的其他部件均可替换原版，如果原版哪里损坏可用作为备件使用。

## 预览 - 带副爪的回转轴

这里是一些带副爪系统回转轴的预览，包括形态的变化的着色图，以及实拍

- **原本形态以及组合形态**
  
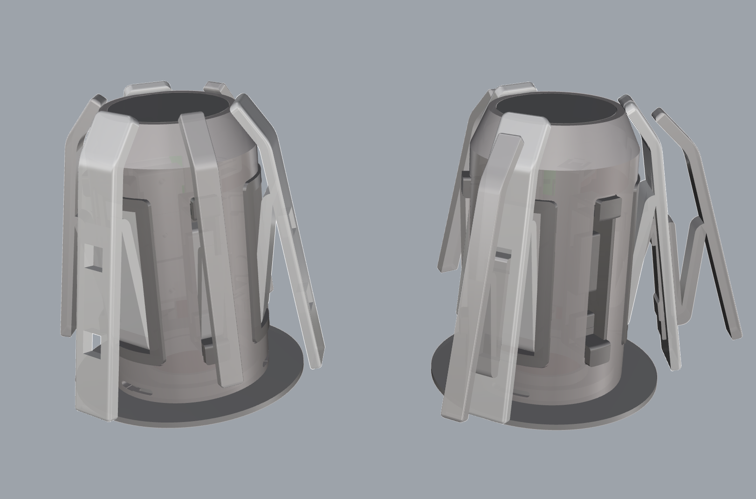
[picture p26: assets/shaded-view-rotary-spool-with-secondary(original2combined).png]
原本形态与组合形态的着色图
  

- **分体图**
  
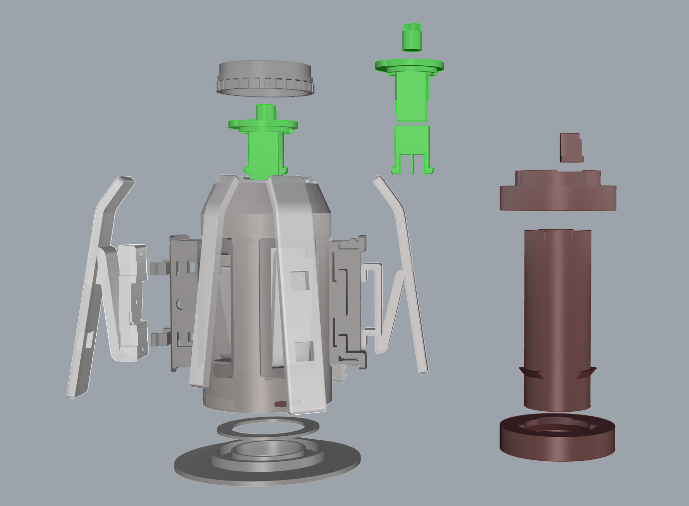
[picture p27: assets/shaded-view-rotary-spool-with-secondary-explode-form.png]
回转轴的分体图
  

- **实拍图**
  
  实拍图 - 原本形态
  实拍图 - 组合形态
  实拍图 - 顶端
  实拍图 - 底端

## 动态展示

### 支持常规尺寸耗材盘中心孔  
回转轴的原本形态（副爪安装在外壳上），适用于大多数耗材品牌，例如 Bambu、Tinmorry 等。  
动态展示 - Origin

### 支持大尺寸耗材盘中心孔  
回转轴的组合形态（副爪安装在主爪上），适用于大尺寸中心孔耗材品牌，例如 Sunlu、Jayo 等。  
动态展示 - Combined

## 所需硬件

此模型需要两个硬件组件才能正常工作：

1. **三波形垫片**  
   - **尺寸**: 27mm x 34mm x 0.4mm  
   - **高度**: 3.1mm  
   - 三波形垫片

2. **扭簧**  
   - **线径**: 0.8mm  
   - **外径**: 9mm  
   - **旋转方向**: 180度左旋/右旋
   - **圈数**： 5
   - 扭簧

## 3MF 文件

为了简化打印过程，提供了3MF文件，您可以直接在 **Orca** 或 **Bambu Studio** 中使用：

- **all-in-one.3mf**: 3MF file for the ratory spool(include secondary claws), all in one plate, include both green and yellow core, you should uncheck one according to yourself.
- **amslite-rotary-spool-with-secondary-claws.3mf**: 包含回转轴（带副爪）的3MF文件， 部件分布在三盘, 第一盘包括底座，外壳，主爪座，主爪；第二盘包括中轴，轴盖，核心（黄色和绿色，选择其中一个），1.2mm的垫片；第三盘包括副爪爪座，副爪。
- **others**: 有五盘， 第一盘包括所有10个规格的垫片，第二盘包括扭簧弯曲模板（包括左右两个版本），第三盘是一体打印的主爪爪座，第四盘是一体打印的核心（包括黄色和绿色），第五盘是一体打印的中轴。

只需在 **Orca** 或 **Bambu Studio** 中打开这些3MF文件，即可开始打印！

## 组装说明

1. **主组件组装**：
   - 首先打印 **base.stl**、**shaft_cover.stl** 和 **shell_with_secondary-claws(thickened).stl** 文件。这些部件是回转轴的基础。
   - **推荐**：建议打印 **shell_with_secondary-claws(thickened).stl**，因为它包括了 **shell(thickened).stl** 的所有功能。如果您以后想要添加副爪系统，在此基础上，您只需添加副爪座和副爪。如果不需要副爪系统，只需使用 **shell_with_secondary-claws(thickened).stl** 即可，无需额外部件。

2. **爪部组件组装**：
   - **basic.stl** 适用于标准回转轴，不能与副爪系统配合使用，因为它没有副爪插槽。
   - 如果您计划使用副爪支撑更大直径的料盘，主爪应使用 **main_claw_with_secondary_slots.stl**，该主爪具有副爪插槽，可以与 **secondary_claw.stl** 配合使用。
   - **secondary_claw.stl** 只能与 **main_claw_with_secondary_slots.stl** 或 **secondary_claw_seat.stl** 配合使用，这些部件带有副爪插槽。
   - **推荐**：建议打印 **main_claw_with_secondary_slots.stl**，因为它包括了 **basic.stl** 的所有功能。如果以后需要副爪系统，只需在此基础上添加副爪，无需重新打印主爪。如果不需要副爪系统，只需使用 **main_claw_with_secondary_slots.stl** 即可，无需额外部件。

3. **爪座组装**：
   - 主爪座和副爪座分别使用 **main_claw_seat.stl** 和 **secondary_claw_seat.stl** 打印。

4. **核心部件**：
   - 如果您希望打印一体化的核心部件，请使用 **green_version.stl**（绿色版本）或 **yellow_version.stl**（黄色版本）。
   - 如果您希望将核心部件分开打印并使用胶水组装，请打印 **green_version_pieces/** 和 **common_pieces/**（绿色版本），或者 **yellow_version_pieces/** 和 **common_pieces/**（黄色版本）。分体打印的优势在于减少支撑材料和优化强度。
   - **common_pieces/** 文件夹包含两个版本核心部件都需要的共享部件，例如扭簧中心和短端卡扣。

5. **压力垫圈**：
   - 根据您的组装需求，从 **gaskets/** 中选择合适的垫圈厚度。

6. **中轴组件**：
   - 中轴组件有两种打印方式：
     - **一体化版本**：**shaft.stl** 是完整的中轴模型，作为单个部件打印。
     - **分体打印版本**：如果您希望将中轴分开打印并用胶水组装，请打印 **shaft_pieces/**

## 许可
本项目采用 [Creative Commons Attribution 4.0 International License](https://creativecommons.org/licenses/by/4.0/)，欢迎修改和分发，但请注明出处。

## 免责声明
请注意，回转轴和副爪系统设计并不适用于承受极高的负载或作为专业工具使用，仅适用于日常3D打印相关的线材管理。

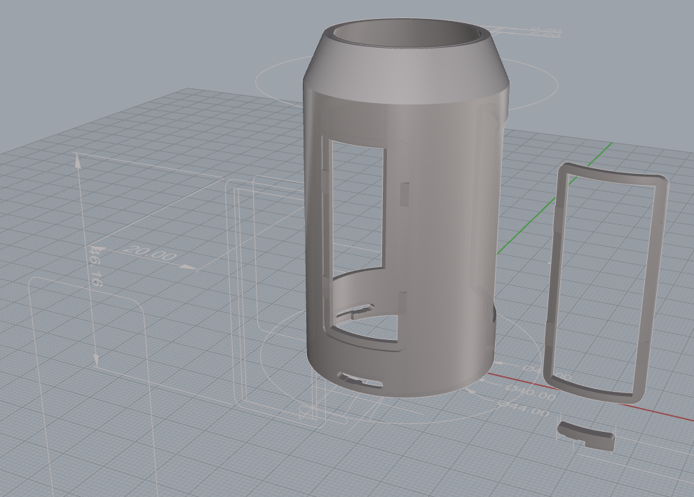
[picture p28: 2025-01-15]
assets/design/shell.png

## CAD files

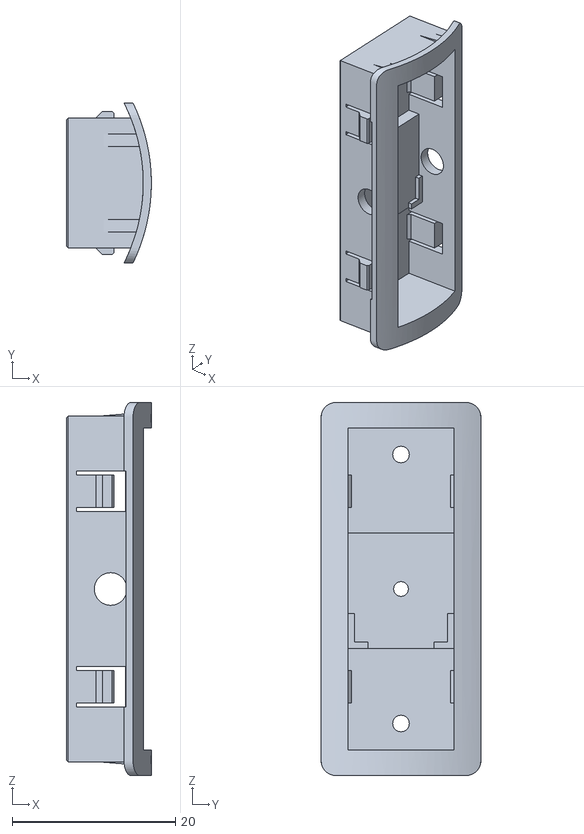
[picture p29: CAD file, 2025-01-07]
stls/bambu_style/claw_seat/main_claw_seat.stl
10.4 x 19.6 x 45.8

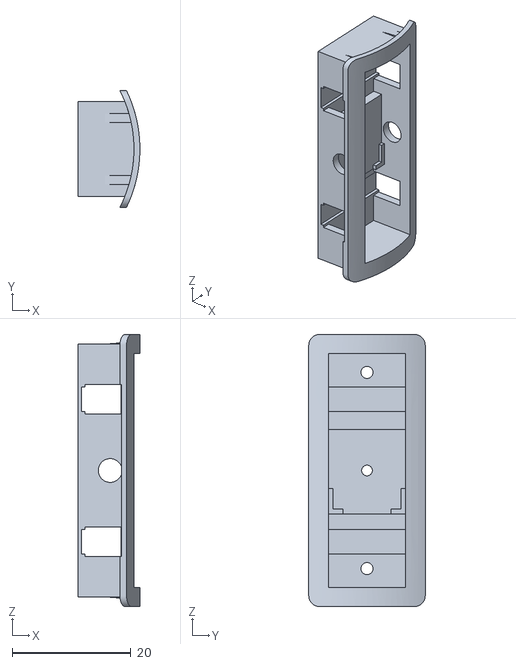
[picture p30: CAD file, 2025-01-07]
stls/bambu_style/claw_seat/main_claw_seat_pieces/main_claw_seat_base.stl
10.4 x 19.6 x 45.8

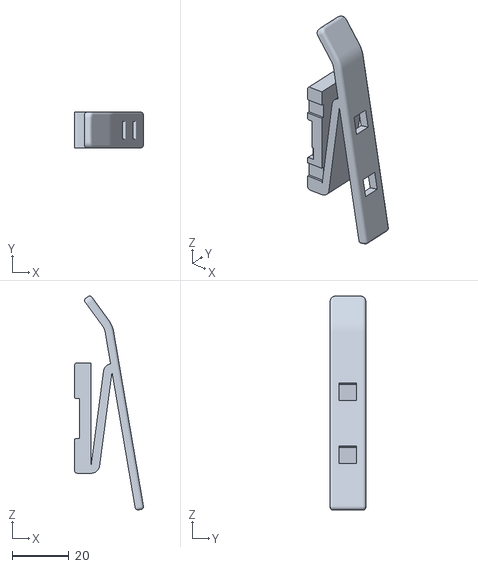
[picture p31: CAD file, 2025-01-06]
stls/bambu_style/claw/main_claw_with_secondary_slots.stl
24.4 x 12.6 x 75.7

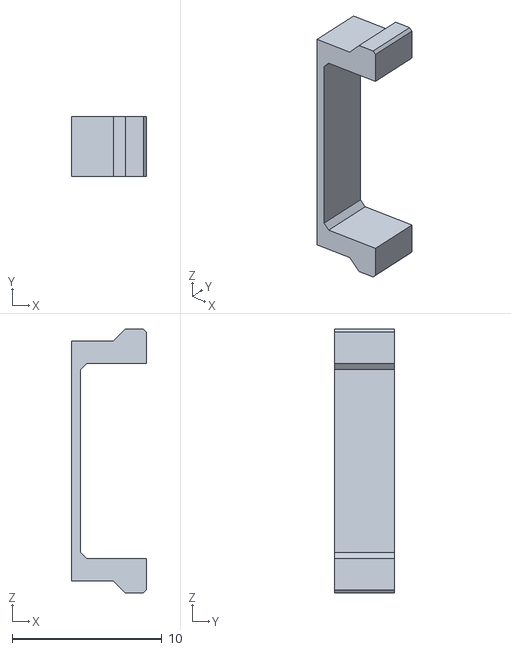
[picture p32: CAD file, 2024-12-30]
stls/bambu_style/claw_seat/main_claw_seat_pieces/main_claw_seat_clip.stl
5.00 x 4.00 x 17.6

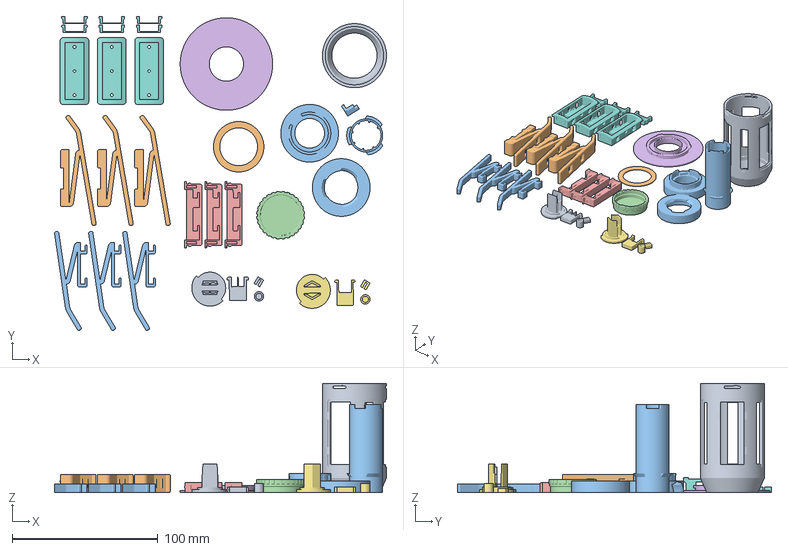
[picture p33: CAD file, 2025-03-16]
3mf/all-in-one.3mf
227.9 x 215.7 x 75.0 mm
shell_with_secondary-claws(thickened).stl
thickness-1.2mm.stl
组合体 x 7
shaft_cover.stl
base.stl

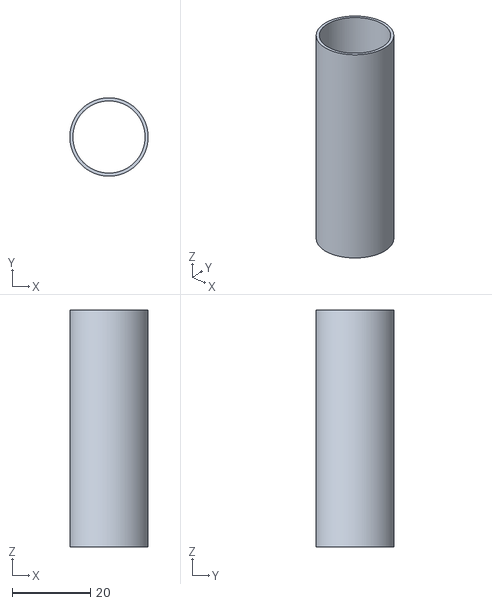
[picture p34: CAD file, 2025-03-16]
stls/[fix-file]shaft-adapter.stl
20.0 x 20.0 x 60.6

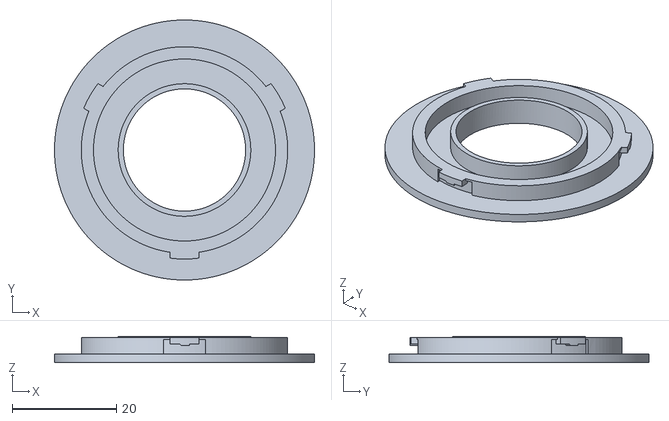
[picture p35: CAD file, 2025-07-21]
stls/bambu_style/base-50mm.stl
50.0 x 50.0 x 5.00

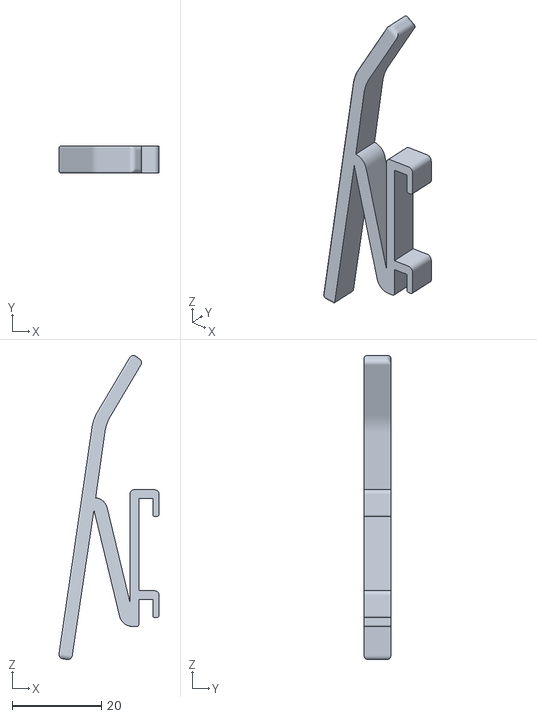
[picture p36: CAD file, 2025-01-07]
stls/bambu_style/claw/secondary_claw.stl
22.4 x 6.00 x 68.0

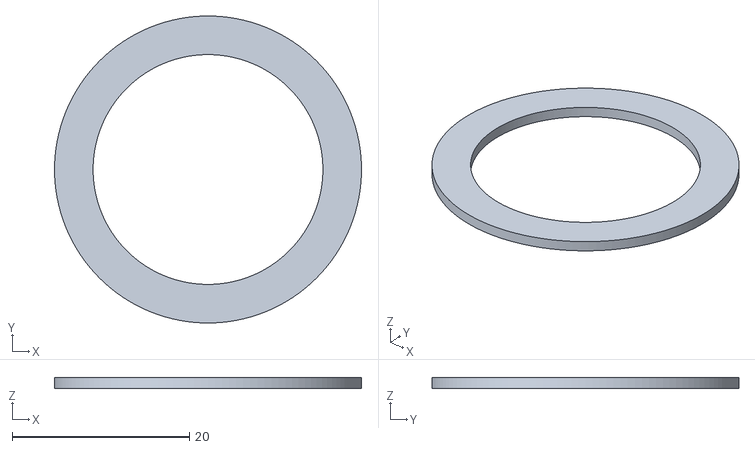
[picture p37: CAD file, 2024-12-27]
stls/bambu_style/pressure_gaskets/thickness-1.2mm.stl
34.6 x 34.6 x 1.20

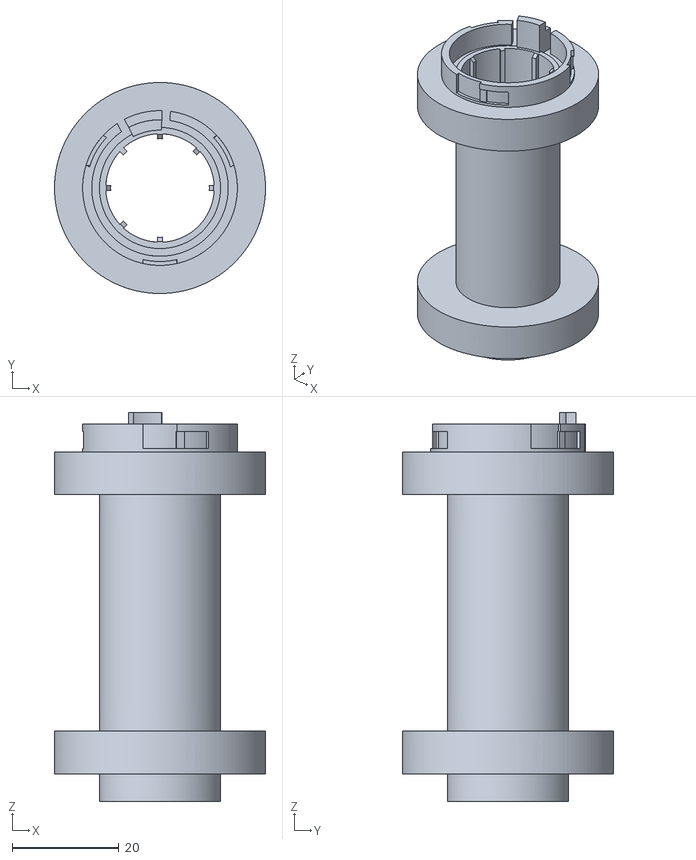
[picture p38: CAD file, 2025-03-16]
stls/bambu_style/shaft/shaft.stl
39.6 x 39.6 x 73.0

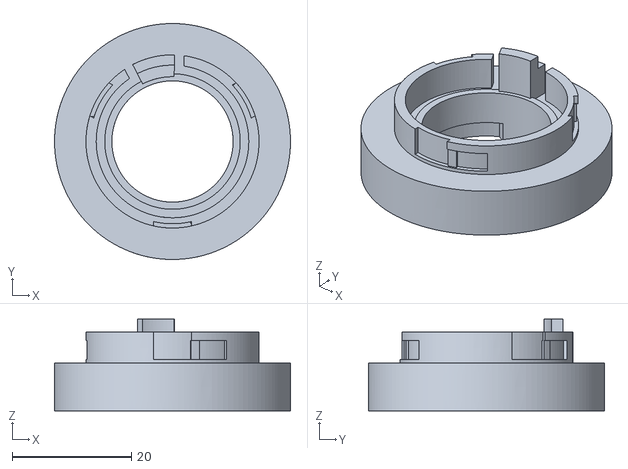
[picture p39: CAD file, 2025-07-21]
stls/bambu_style/shaft/shaft_pieces/top_disc_contact_core-torsion_spring_long_end_clip.stl
39.6 x 39.6 x 15.4

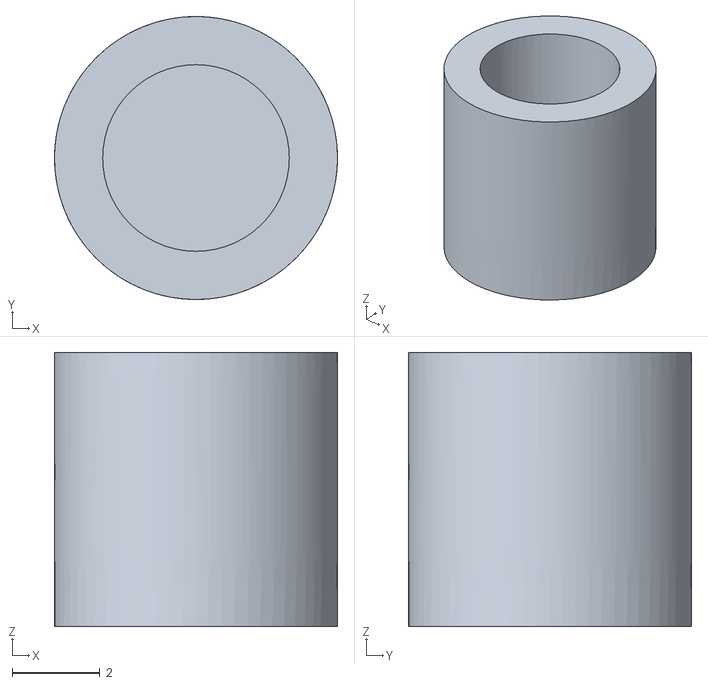
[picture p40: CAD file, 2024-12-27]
stls/core_parts/common_pieces/torsion_spring_center.stl
6.46 x 6.46 x 6.26

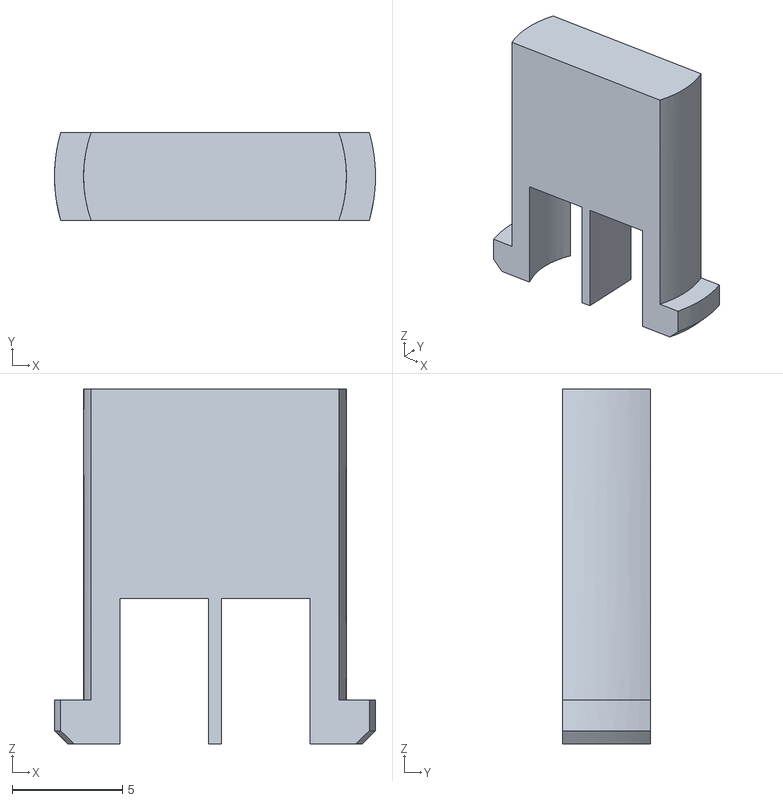
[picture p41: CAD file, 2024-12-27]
stls/core_parts/green_version_pieces/core_fixed_clip.stl
14.6 x 4.00 x 16.1

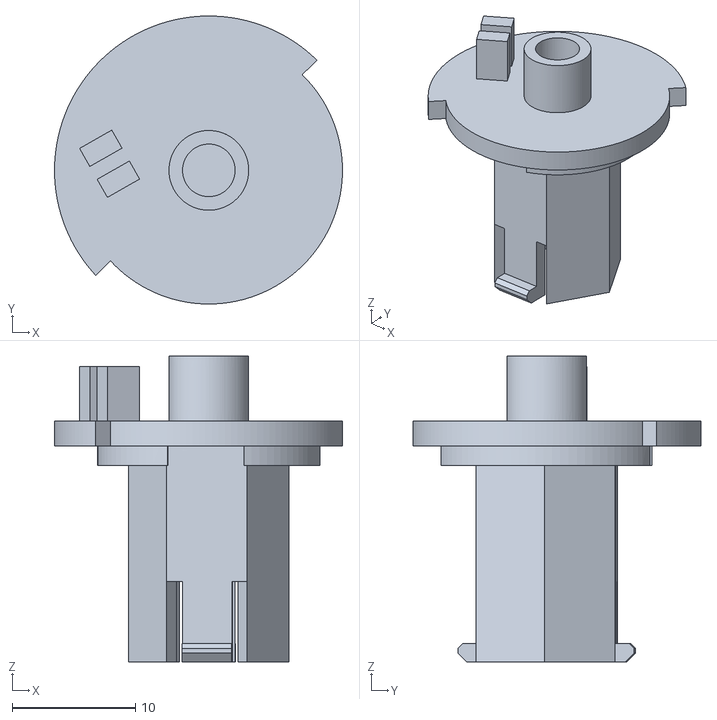
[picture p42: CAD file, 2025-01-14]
stls/core_parts/yellow_version.stl
23.3 x 23.3 x 24.8

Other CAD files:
stls/core_parts/yellow_version_pieces/core_fixed_clip.stl
stls/holder/D18_L160mm(with-core-clip-slots).stl
stls/holder/scree_on_clockwise_pieces/yellow(with-core-clip-slots).stl
stls/shaft_cover/cap_with_number/cap_with_number1.stl
3mf/ams-riser-v2-ams-lite-rotary-holder-withAMS.3mf
3mf/ams-riser-v2-ams-lite-rotary-holder.3mf
3mf/amslite-rotary-spool-with-secondary-claws.3mf
3mf/amslite-spool-holder-cap-with-number.3mf
3mf/debug-bambu-style.3mf
3mf/debug-universal.3mf
3mf/gaskets.3mf
3mf/others.3mf
3mf/torsion-spring-bending-template.3mf
3mf/universal-amslite-rotary-spool-holder-with-auto-rewind.3mf
3mf/universal-others.3mf
stls/bambu_style/base.stl
stls/bambu_style/claw/basic.stl
stls/bambu_style/claw_seat/secondary_claw_seat.stl
stls/bambu_style/pressure_gaskets/thickness-0.2mm.stl
stls/bambu_style/pressure_gaskets/thickness-0.4mm.stl
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

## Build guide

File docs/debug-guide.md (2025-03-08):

# How to Debug

## Debug Files
1. **Bambu Style**: [debug-bambu-style.3mf](../3mf/debug-bambu-style.3mf)
2. **Universal Version**: [debug-universal.3mf](../3mf/debug-universal.3mf)

## What Does Proper Pressure Look Like?
The rotary shaft should function as follows:
1. The core part rotates first.
2. Once the torsion spring reaches its limit and can no longer rotate, the outer shell starts to rotate.

Therefore, the three-wave gasket must provide sufficient friction. If the friction is too low, the outer shell will start rotating too early, reducing the overall rotation angle.

## How to Use Different Thickness Gaskets
The `debug-bambu-style.3mf` and `debug-universal.3mf` files include a perforated cover and four gasket thickness options:
- **0.2mm**
- **0.4mm**
- **0.8mm**
- **1.6mm**

By combining these gaskets, the following thicknesses can be achieved:

| Combination | Thickness (mm) |
|---|---|
| 0.2 | 0.2 |
| 0.4 | 0.4 |
| 0.2 + 0.4  | 0.6 |
| 0.8 | 0.8 |
| 0.2 + 0.8  | 1.0 |
| 0.4 + 0.8  | 1.2 |
| 0.2 + 0.4 + 0.8 | 1.4 |
| 1.6 | 1.6 |
| 0.2 + 1.6  | 1.8 |
| 0.4 + 1.6  | 2.0 |
| 0.2 + 0.4 + 1.6 | 2.2 |
| 0.8 + 1.6  | 2.4 |
| 0.2 + 0.8 + 1.6 | 2.6 |
| 0.4 + 0.8 + 1.6 | 2.8 |
| 0.2 + 0.4 + 0.8 + 1.6 | 3.0 |

## How to Determine the Right Gasket Thickness Using the Perforated Cover
The provided perforated cover model allows you to observe the torsion spring’s movement through the opening, helping to select the correct gasket thickness.

### Selection Method:
1. Start with a thinner gasket.
2. Observe the core rotation:
   - **If the outer shell starts rotating before the core reaches its limit**, the gasket thickness is insufficient, and you need to increase it.
   - **If the outer shell starts rotating only after the core reaches its limit**, the balance is correct.
   - Below image provide you a sample of the position:
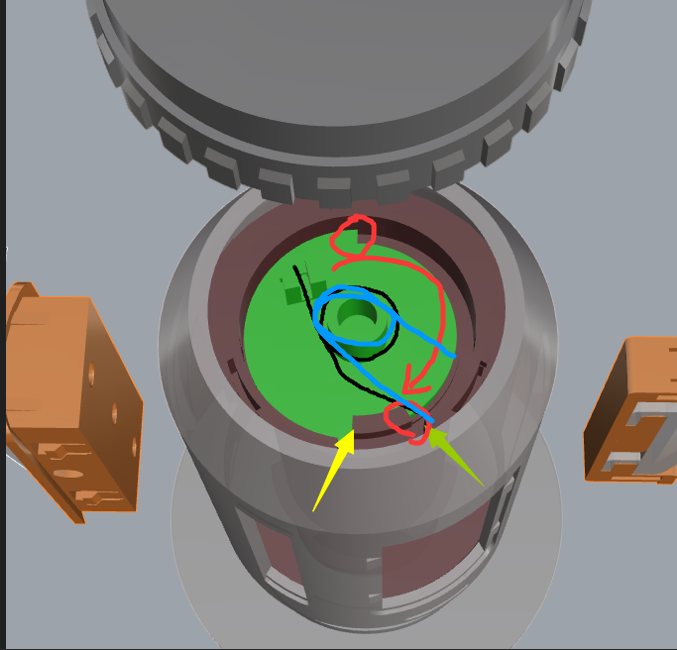
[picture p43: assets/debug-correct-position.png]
      - 
      - The image uses a green core as an example.
      - Black represents the initial torsion spring position.
      - Red indicates the core’s rotation direction.
      - Blue marks the torsion spring’s final position.
3. Gradually increase the gasket thickness until you find the optimal balance.

**Example:**
- You first test with a **1.2mm** combination and notice that the outer shell starts rotating before the core fully reaches its limit.
- Then, you try **1.4mm**, but the issue persists.
- Increasing to **1.6mm**, you see that the core reaches its limit before the outer shell rotates, indicating that **1.6mm is the correct thickness**.

By following this process, you can fine-tune the gasket thickness to ensure the rotary shaft functions properly.

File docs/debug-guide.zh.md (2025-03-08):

# 如何 Debug

## Debug 文件
1. **Bambu Style**：[debug-bambu-style.3mf](../3mf/debug-bambu-style.3mf)
2. **Universal Version**：[debug-universal.3mf](../3mf/debug-universal.3mf)

## 什么样子是压力合适？
回转轴正常的工作情况是：
1. 先旋转核心部分。
2. 扭簧转到位，无法继续旋转后，外壳才开始旋转。

因此，三波峰垫片需要提供足够的摩擦力。如果摩擦力不足，外壳会提前旋转，导致回转角度变小。

## 如何使用不同厚度的垫片
在 `debug-bambu-style.3mf` 和 `debug-universal.3mf` 文件中，包含了一个镂空盖子和四种厚度的垫片：
- **0.2mm**
- **0.4mm**
- **0.8mm**
- **1.6mm**

通过组合这些垫片，可以实现以下厚度：

| 组合方式  | 厚度 (mm) |
|---|---|
| 0.2 | 0.2 |
| 0.4 | 0.4 |
| 0.2 + 0.4 | 0.6 |
| 0.8 | 0.8 |
| 0.2 + 0.8 | 1.0 |
| 0.4 + 0.8 | 1.2 |
| 0.2 + 0.4 + 0.8 | 1.4 |
| 1.6 | 1.6 |
| 0.2 + 1.6 | 1.8 |
| 0.4 + 1.6 | 2.0 |
| 0.2 + 0.4 + 1.6 | 2.2 |
| 0.8 + 1.6 | 2.4 |
| 0.2 + 0.8 + 1.6 | 2.6 |
| 0.4 + 0.8 + 1.6 | 2.8 |
| 0.2 + 0.4 + 0.8 + 1.6 | 3.0 |

## 如何利用镂空盖子确定合适的垫片厚度
项目提供的镂空盖子模型，可以通过观察镂空缝隙内的扭簧旋转情况，帮助选择合适的垫片厚度。

### 选择方法：
1. 先从较薄的垫片组合开始测试。
2. 观察核心旋转情况：
   - **如果核心尚未转到头，外壳就开始旋转**，说明垫片厚度不足，需要增加厚度。
   - **如果核心转到位后，外壳才开始旋转**，说明达到了合适的平衡。
   - 这张图片提供了位置的示例
     - 
     - 以绿色核心为示例
     - 黑色表示初始扭簧位置
     - 红色表示核心旋转方向
     - 蓝色表示扭簧最终位置
3. 逐步增加垫片厚度，直到找到最佳平衡点。

**示例：**
- 你先尝试 **1.2mm** 组合，发现核心未完全转到头时外壳就开始旋转。
- 然后尝试 **1.4mm**，问题仍然存在。
- 继续增加到 **1.6mm**，发现核心先到位后，外壳才旋转，说明 **1.6mm 是合适的厚度**。

通过这个方法，你可以精确调整垫片厚度，确保回转轴正常工作。

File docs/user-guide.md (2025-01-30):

# User Guide

Welcome to this guide! This user manual provides you with detailed steps and precautions to help you perform various tasks smoothly.

## Table of Contents

- [User Guide](#user-guide)
  - [Table of Contents](#table-of-contents)
  - [1. Part Assembly with Glue](#1-part-assembly-with-glue)
    - [1.1 Potential Parts and Glue Application Positions](#11-potential-parts-and-glue-application-positions)
      - [1.1.1 Main Claw Seat](#111-main-claw-seat)
      - [1.1.2 Green Core](#112-green-core)
      - [1.1.3 Yellow Core](#113-yellow-core)
      - [1.1.4 Shaft](#114-shaft)
    - [1.2 Assembly Steps](#12-assembly-steps)
    - [1.3 Notes](#13-notes)
  - [2. Grease Application Positions](#2-grease-application-positions)
    - [2.1 Shaft](#21-shaft)
  - [3. Use of Torsion Spring Mould](#3-use-of-torsion-spring-mould)
  - [4. Rotary Spool Holder Installation](#4-rotary-spool-holder-installation)
    - [4.1 Bambu Version](#41-bambu-version)
      - [4.1.1 Prepared Printed Parts](#411-prepared-printed-parts)
      - [4.1.2 Prepared Hardware](#412-prepared-hardware)
      - [4.1.3 Installation Steps](#413-installation-steps)
    - [4.2 Universal Version](#42-universal-version)
      - [4.2.1 Prepared Printed Parts](#421-prepared-printed-parts)
      - [4.2.2 Prepared Hardware](#422-prepared-hardware)
      - [4.2.3 Installation Steps](#423-installation-steps)
  - [Feedback and Issue Reporting](#feedback-and-issue-reporting)

## 1. Part Assembly with Glue

### 1.1 Potential Parts and Glue Application Positions

When printing in parts and assembling, certain areas require glue to ensure firm adhesion. Refer to the following sections to understand the glue application positions for each part.

*The red areas on the images indicate where the glue should be applied.*

#### 1.1.1 Main Claw Seat

- **Base and Clip:** Apply glue to the contact surface between the base and the clip of the main claw seat to ensure a strong bond.

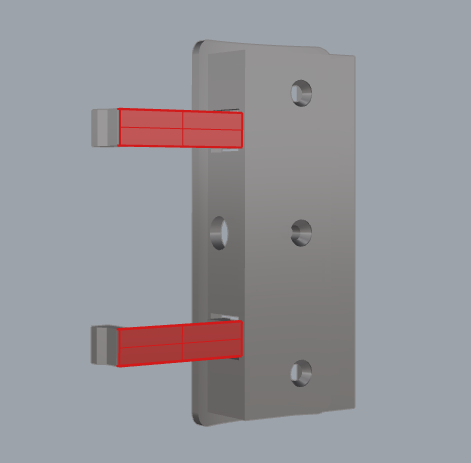
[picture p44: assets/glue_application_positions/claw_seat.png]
Glue application - Main Claw Seat Base and Clip


#### 1.1.2 Green Core

- **Claw Holder Components:** Apply glue to the claw holder components of the green core to ensure they are securely fixed.
- **Torsion Spring Center Fixation:** Apply glue to the contact area between the torsion spring center and the core to ensure the torsion spring is firmly attached.
- **Torsion Spring Short End Fixation:** Apply glue to the contact area between the short end of the torsion spring and the core to ensure secure fixation.

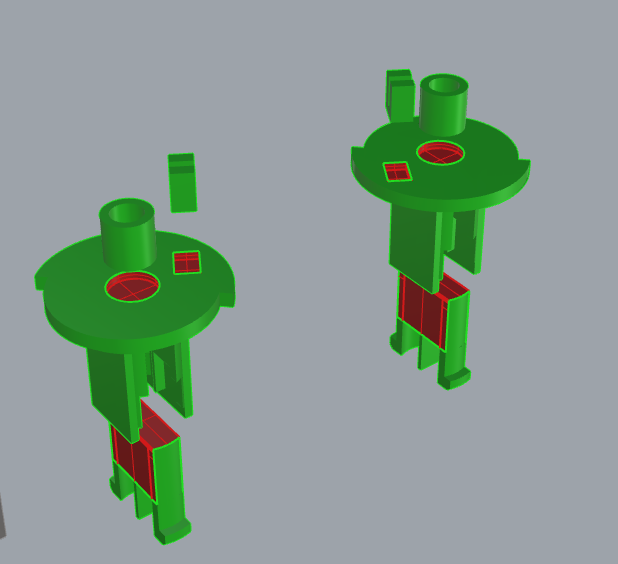
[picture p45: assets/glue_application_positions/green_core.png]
Glue Application - Green Core


#### 1.1.3 Yellow Core

- **Claw Holder Components:** Apply glue to the claw holder components of the yellow core to ensure they are securely fixed.
- **Torsion Spring Center Fixation:** Apply glue to the contact area between the torsion spring center and the core to ensure the torsion spring is firmly fixed.
- **Torsion Spring Short End Fixation:** Apply glue to the contact area between the short end of the torsion spring and the core to ensure secure fixation.

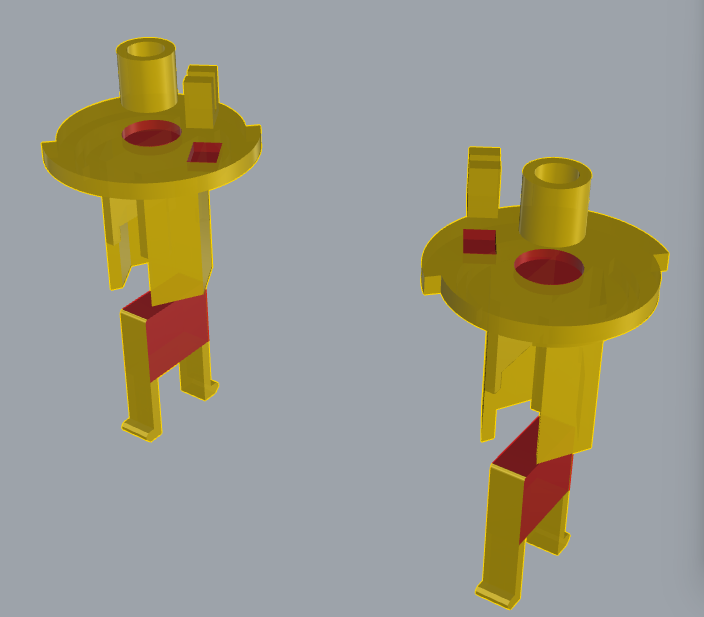
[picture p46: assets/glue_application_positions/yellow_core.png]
Glue Application - Yellow Core


#### 1.1.4 Shaft

- **Round Rod:** Apply glue to the contact points between the round rod of the shaft and other connecting components.
- **Top Spacer and Torsion Spring Long End Fixation:** Apply glue to the contact area between the top spacer and the long end of the torsion spring to ensure a stable connection.

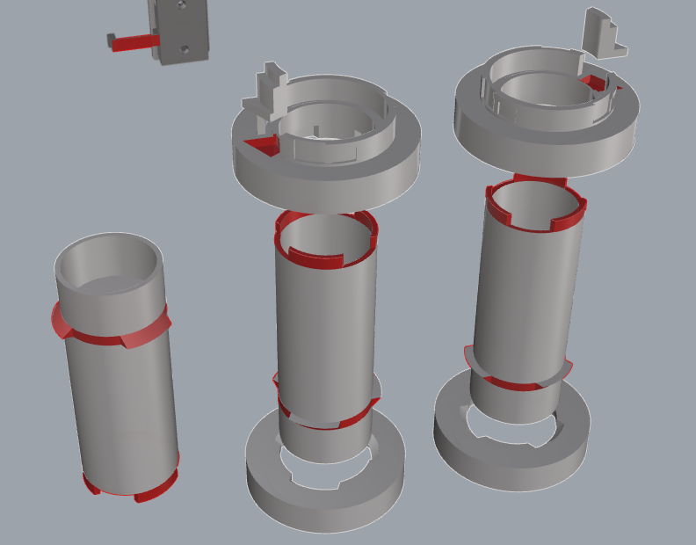
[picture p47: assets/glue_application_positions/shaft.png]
Glue Application - shaft


### 1.2 Assembly Steps

1. **Choose the right glue:** Use strong glue suitable for plastic or 3D printed parts.
2. **Apply glue:** Evenly apply glue to the areas marked in the images above.
3. **Assemble parts:** Quickly align and press the parts with glue applied, ensuring each part fits tightly without gaps.
4. **Wait for the glue to cure:** Follow the instructions on the glue packaging and wait for the glue to cure to ensure firm adhesion.

### 1.3 Notes

- Do not apply too much glue to avoid overflow, which could affect appearance or cause weak adhesion.
- Use quick-drying glue to shorten the waiting time and improve assembly efficiency.
- Ensure all parts are completely cooled before assembling to ensure the glue is fully cured.
- Always work in a well-ventilated area to avoid inhaling glue fumes.
- Use protective gloves to avoid direct contact with glue, preventing allergies or skin irritation.
- Use protective mats or waste paper to prevent glue spills from dirtying the work surface or other parts.

## 2. Grease Application Positions

Proper lubrication helps ensure smooth operation of various parts, reducing friction and wear. Refer to the following sections to understand where grease should be applied:

- Apply grease to the contact areas between the core and the shaft to ensure smooth operation of the torsion spring.
- Apply a proper amount of grease to the two circular discs where the shaft contacts the shell to reduce friction.

*The blue areas in the images indicate where the grease should be applied.*

### 2.1 Shaft

The image below shows where grease needs to be applied to the shaft. Apply the grease evenly to reduce friction and ensure smooth rotation:

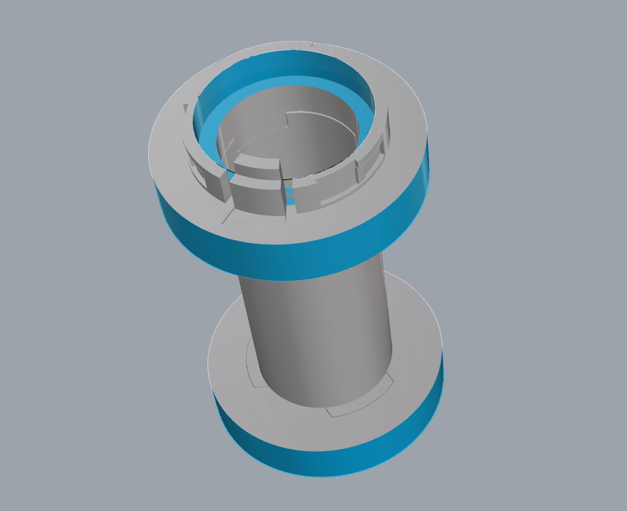
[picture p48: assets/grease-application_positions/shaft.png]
Grease application - Shaft


## 3. Use of Torsion Spring Mould

Creating torsion springs of suitable shapes can be aided by a torsion spring bending mould. Here are the steps for using the torsion spring bending mould:

1. The bending template is provided as a [3mf file](../3mf/torsion-spring-bending-template.3mf) in the warehouse. Print the corresponding disc based on the torsion spring direction.
2. Prepare the torsion spring to be bent, place it in the designated grooves of the mould.
3. Use appropriate tools to apply force, bending the wire beyond 90 degrees.
4. Cut off any excess wire.
5. Continue applying force until the wire is bent close to 180 degrees.
6. Remove the torsion spring from the mould and use pliers to adjust the spring shape.

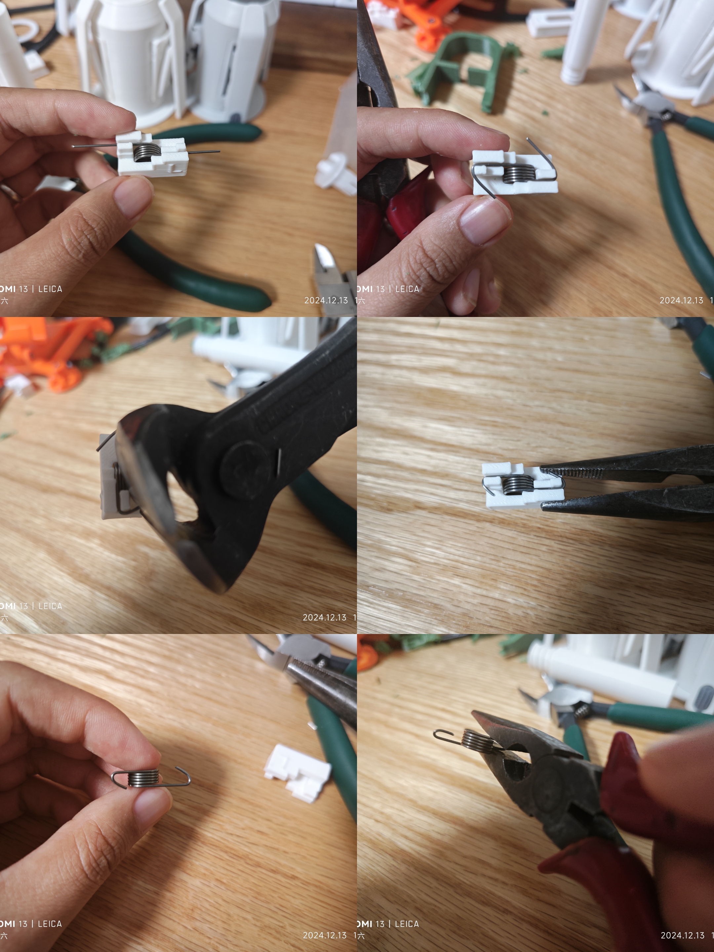
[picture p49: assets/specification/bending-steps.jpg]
Torsion Spring Bending Steps


## 4. Rotary Spool Holder Installation

### 4.1 Bambu Version

If printed in parts, assume the parts have already been glued together.

#### 4.1.1 Prepared Printed Parts

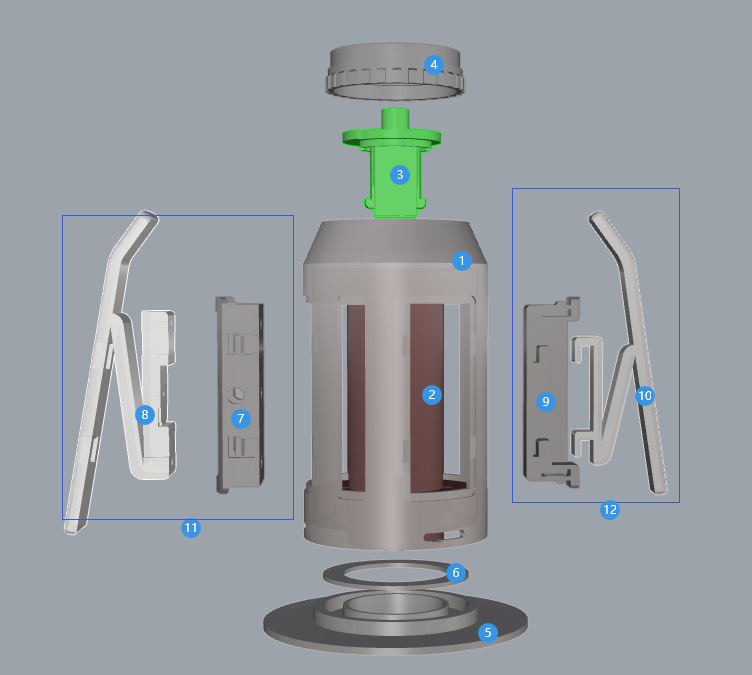
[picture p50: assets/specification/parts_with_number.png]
All Printed Parts


Numbers in the image:

1. Shell
2. Shaft
3. Green core (choose green or yellow according to your needs)
4. Shaft cover
5. Base
6. Gasket (default thickness 1.2mm, different thicknesses available)
7. Main claw seat (*3)
8. Main claw with secondary claw installation slot (*3)
9. Secondary main claw seat (0 / *3)
10. Secondary claw (0 / *3)

Secondary claw is optional, so the quantity is 0 or 3.

#### 4.1.2 Prepared Hardware

1. Bent torsion spring
2. Three-wave gasket M27*34mm

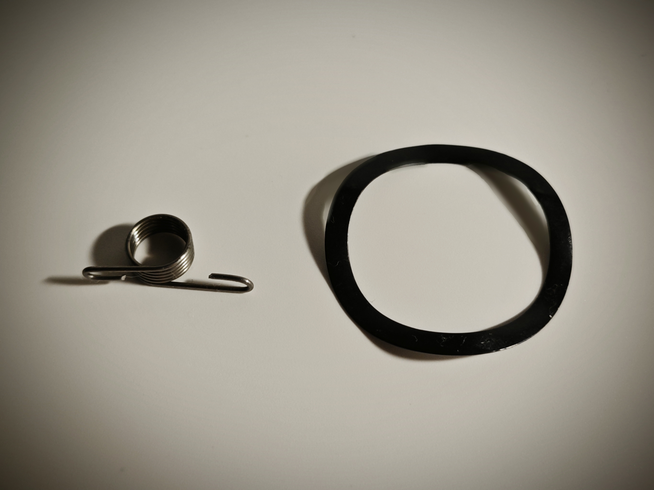
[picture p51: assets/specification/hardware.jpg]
Hardware


#### 4.1.3 Installation Steps

1. Assemble the claw seats and claws in the correct order and direction.
   1. The main claw seat has a small internal protrusion. Note the installation direction. Push the main claw into the claw seat. The provided clearance should allow the claw to be securely fixed in the seat. If there is any looseness, there are pre-drilled m1.6 screw holes in the model. You can use m1.6*5 countersunk screws for fixation.

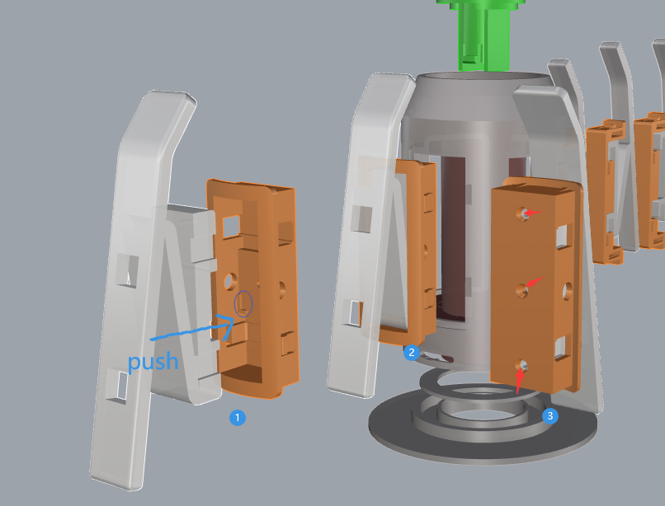
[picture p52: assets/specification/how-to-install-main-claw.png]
How to Assemble the Main Claw
      

   2. Push the secondary claw flat as shown in the image and pull it down.

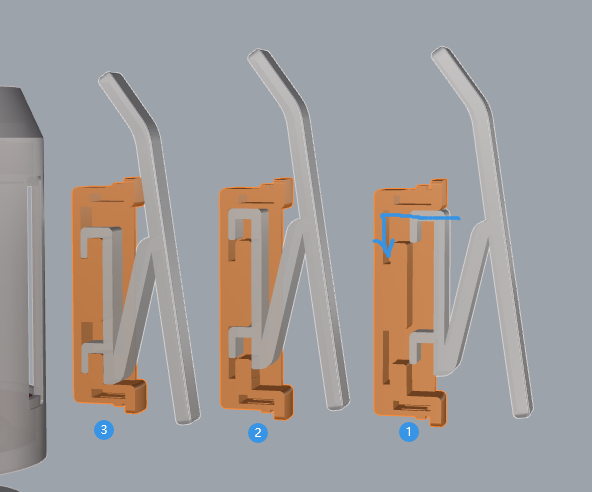
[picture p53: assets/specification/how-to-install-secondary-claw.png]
How to Assemble the Secondary Claw
      

2. Insert the green/yellow core into the shaft (apply lubricant to the corresponding position).
3. Fix the torsion spring (example with green core):

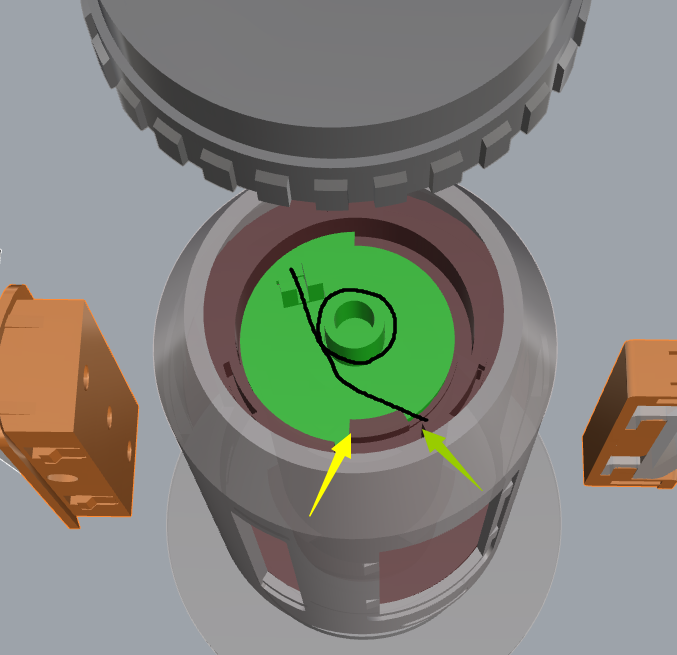
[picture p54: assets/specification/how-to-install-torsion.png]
How to Fix the Torsion Spring
   

4. Install the shaft cover. Align the grooves, press the cover down, and rotate the cover to the right.

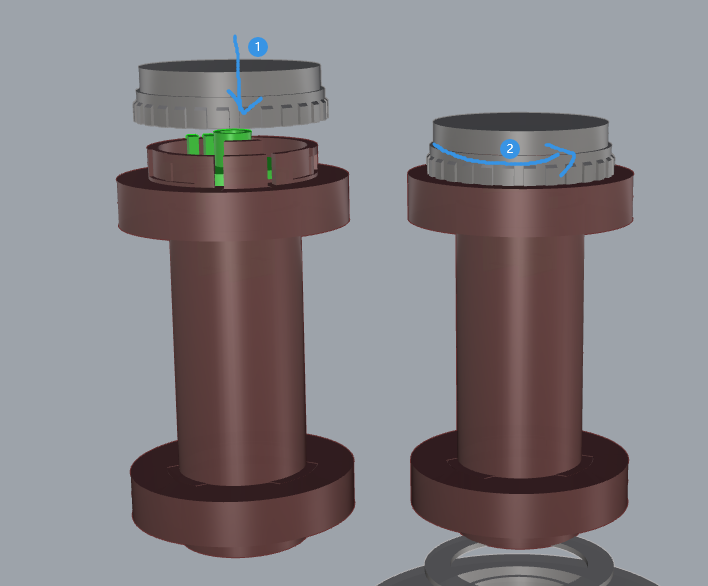
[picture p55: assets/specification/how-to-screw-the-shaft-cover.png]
How to Tighten the Shaft Cover
   

5. Insert the shaft into the shell (apply lubricant to the corresponding positions).
6. Place the spacer into the base and insert the three-peak washer.

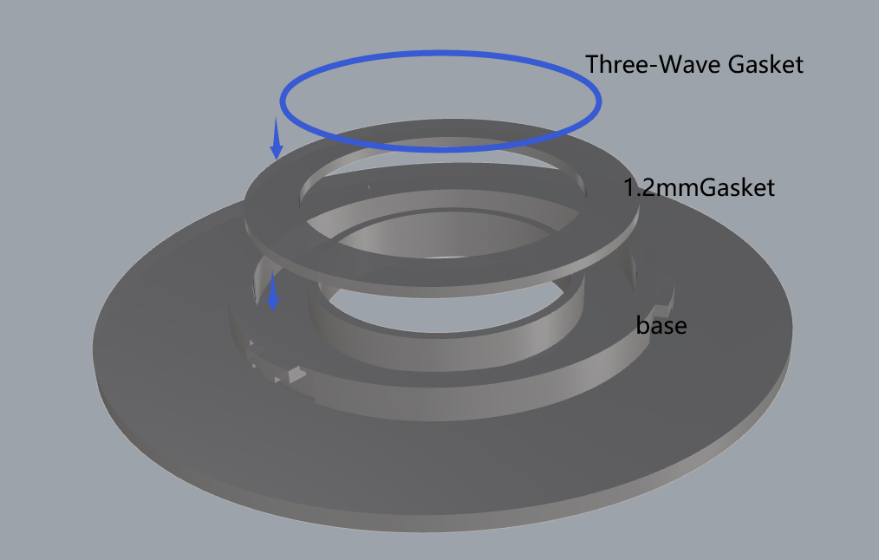
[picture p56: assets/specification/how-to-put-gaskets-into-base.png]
Spacer and Base
   

7. Align the bottom groove of the shell with the protrusion on the base. Press the shell down and rotate it to the right.

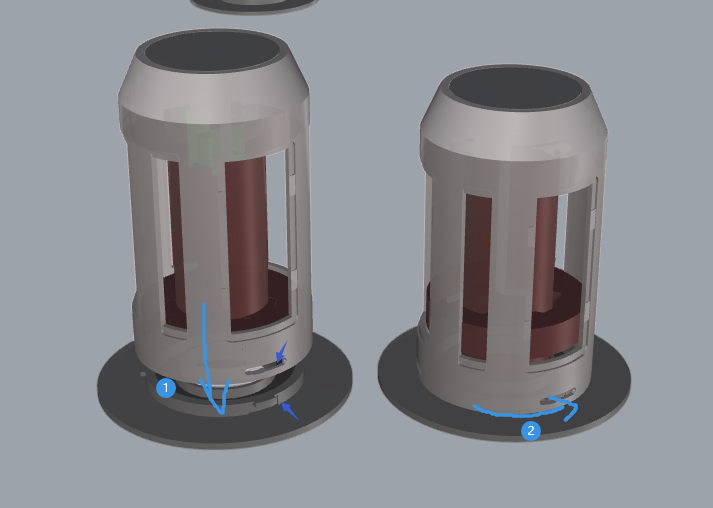
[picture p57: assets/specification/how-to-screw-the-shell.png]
How to Tighten the Shell and Base
   

8. Install the main claw in the corresponding large slot on the shell.

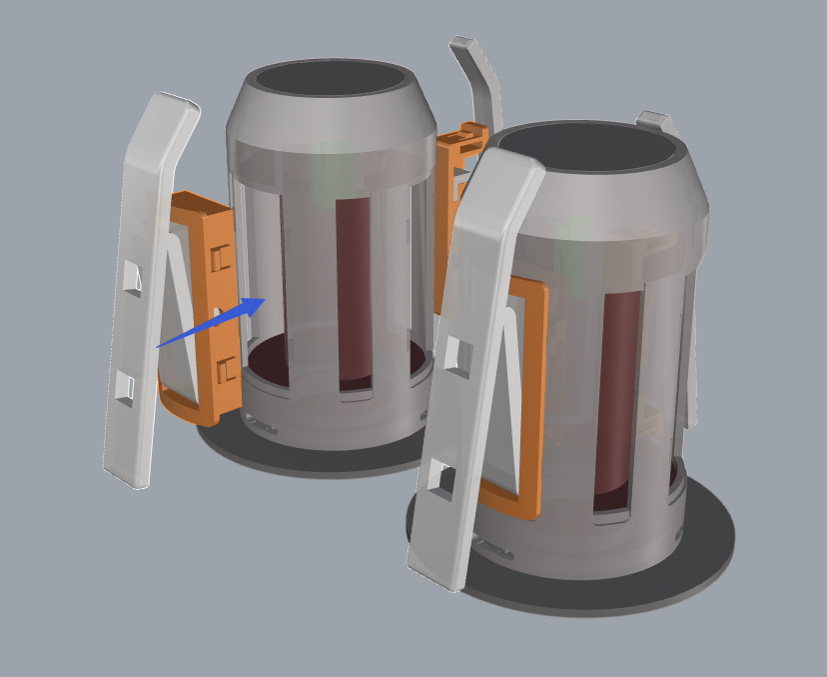
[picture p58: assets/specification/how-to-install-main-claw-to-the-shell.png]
How to Install the Main Claw on the Shell
   

9. Install the secondary claw in the corresponding small slot on the shell (optional).

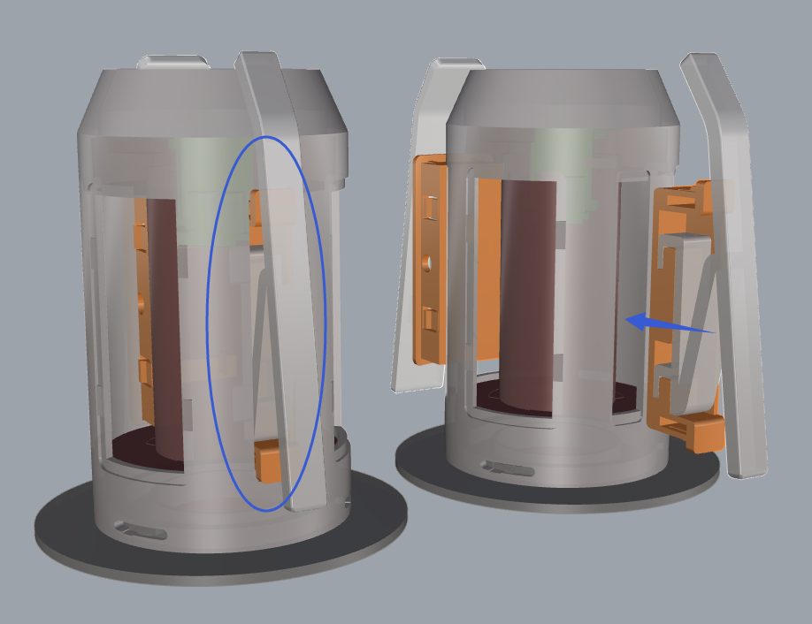
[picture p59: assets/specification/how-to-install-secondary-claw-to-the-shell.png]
How to Install the Secondary Claw on the Shell
   

### 4.2 Universal Version

If printed in parts, assume the parts have already been glued together.

#### 4.2.1 Prepared Printed Parts

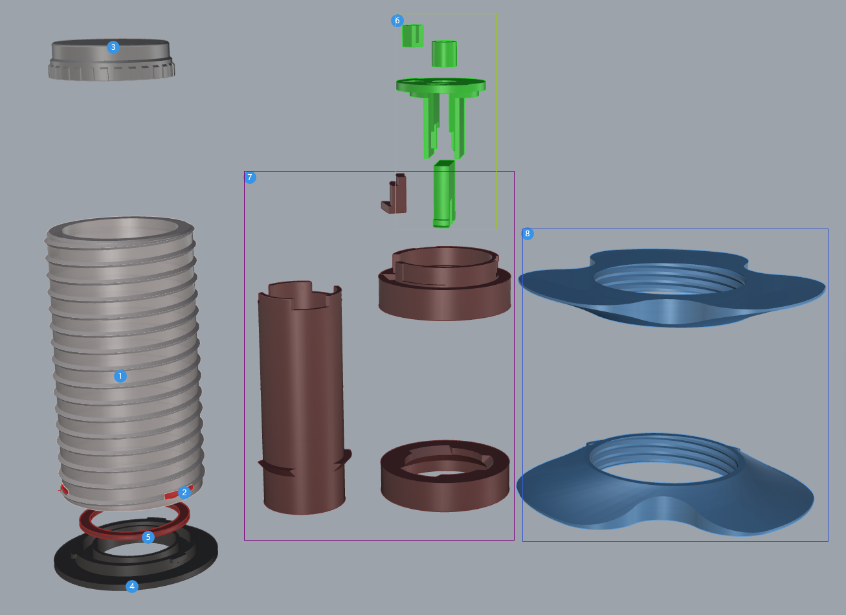
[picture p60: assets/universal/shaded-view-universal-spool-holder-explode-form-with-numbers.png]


Numbers in the image:

1. Shell
2. Shell support (to be removed, remove it before installation)
3. Shaft cover
4. Base
5. Gasket (default thickness 1.2mm, different thicknesses available)
6. Green core (choose green or yellow according to your needs)
7. shaft
8. Spool locking nut (height 8mm, maximum outer diameter 80mm)

#### 4.2.2 Prepared Hardware

1. Bent torsion spring
2. Three-wave gasket M25*31mm

Hardware

#### 4.2.3 Installation Steps

1. Insert the green/yellow core into the shaft (apply lubricant to the corresponding position).
2. Fix the torsion spring (example with green core):

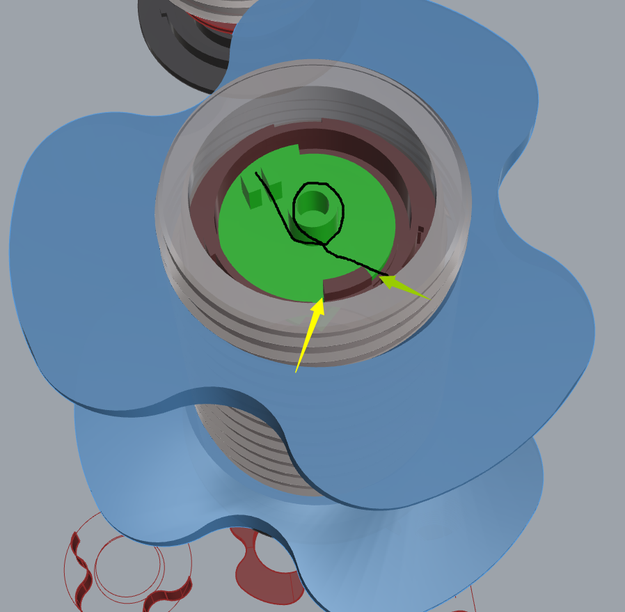
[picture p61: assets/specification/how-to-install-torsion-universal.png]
How to Fix the Torsion Spring
   

3. Install the shaft cover. Align the grooves, press the cover down, and rotate the cover to the right.

   How to Tighten the Shaft Cover

4. Insert the shaft into the shell (apply lubricant to the corresponding positions).
5. Place the spacer into the base and insert the three-peak washer.

   Spacer and Base

6. Align the bottom groove of the shell with the protrusion on the base. Press the shell down and rotate it to the right.

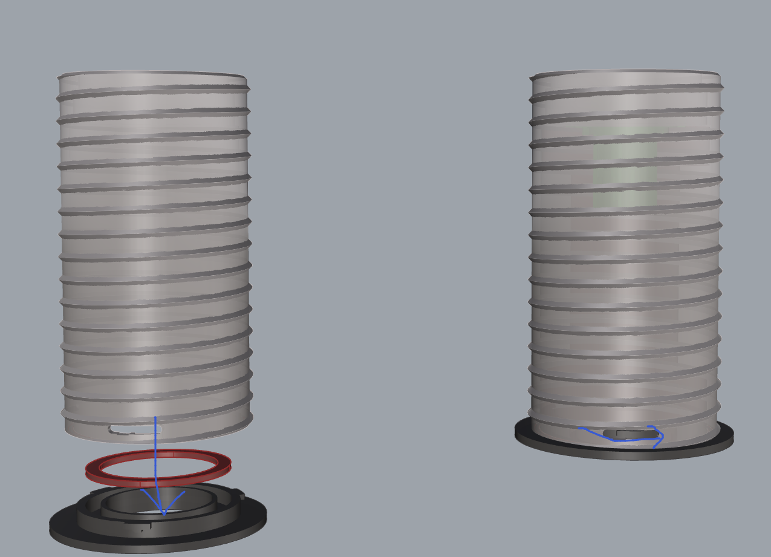
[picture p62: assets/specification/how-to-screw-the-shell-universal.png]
How to Tighten the Shell and Base
   

7. Rotate one spool locking nut onto the shell. After that, insert the spool and then rotate another spool locking nut. Pay attention to the taper direction. Lock it tight after inserting the spool.

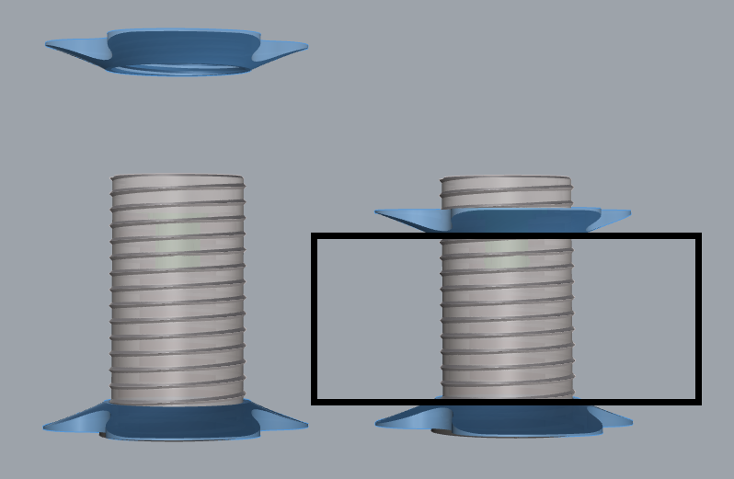
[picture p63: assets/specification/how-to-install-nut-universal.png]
How to Install the Nut on the Shell
   

## Feedback and Issue Reporting

If you encounter any problems during use or have any questions about the model, feel free to submit an [Issue](https://github.com/zjoycelee/amslite-rotary-spool/issues) on this project.

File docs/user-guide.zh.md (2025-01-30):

# 用户指南

欢迎使用本指南！本用户指南为您提供了详细的操作步骤和注意事项，帮助您顺利进行各类操作。

## 目录

- [用户指南](#用户指南)
  - [目录](#目录)
  - [1. 分件胶水组装](#1-分件胶水组装)
    - [1.1 有哪些可能的分件及胶水涂抹位置说明](#11-有哪些可能的分件及胶水涂抹位置说明)
      - [1.1.1 主爪座](#111-主爪座)
      - [1.1.2 绿色核心](#112-绿色核心)
      - [1.1.3 黄色核心](#113-黄色核心)
      - [1.1.4 中轴](#114-中轴)
    - [1.2 组装步骤](#12-组装步骤)
    - [1.3 注意事项](#13-注意事项)
  - [2. 润滑脂涂抹位置](#2-润滑脂涂抹位置)
    - [2.1 中轴](#21-中轴)
  - [3. 扭簧模具使用](#3-扭簧模具使用)
  - [4. 回转轴安装](#4-回转轴安装)
    - [4.1 拓竹风格版本](#41-拓竹风格版本)
      - [4.1.1 准备好的打印件](#411-准备好的打印件)
      - [4.1.2 准备好五金件](#412-准备好五金件)
      - [4.1.3 安装步骤](#413-安装步骤)
    - [4.2 通用版本](#42-通用版本)
      - [4.2.1 准备好的打印件](#421-准备好的打印件)
      - [4.2.2 准备好五金件](#422-准备好五金件)
      - [4.2.3 安装步骤](#423-安装步骤)
  - [反馈与问题报告](#反馈与问题报告)

## 1. 分件胶水组装

### 1.1 有哪些可能的分件及胶水涂抹位置说明

在分件打印并进行组装时，某些部位需要涂抹胶水以确保牢固的粘合。请参考以下部分了解分件的胶水涂抹位置。

*图中红色的部分是需要涂抹胶水的位置。*

#### 1.1.1 主爪座

- **底座和卡子:** 在主爪座的底座和卡子接触面涂抹胶水，确保这些部件牢固粘合。

胶水涂抹 - 主爪座底座和卡子

#### 1.1.2 绿色核心

- **卡子部件:** 在绿色核心的卡子部分涂抹胶水，确保它们牢固固定。
- **扭簧中心固定:** 在扭簧中心和核心接触的地方涂抹胶水，确保扭簧牢固附着。
- **扭簧短端固定:** 在扭簧短端与核心接触的地方涂抹胶水，确保固定良好。

胶水涂抹 - 绿色核心

#### 1.1.3 黄色核心

- **卡子部件:** 在黄色核心的卡子部分涂抹胶水，确保它们牢固固定。
- **扭簧中心固定:** 在扭簧中心和核心接触的地方涂抹胶水，确保扭簧牢固固定。
- **扭簧短端固定:** 在扭簧短端与核心接触的地方涂抹胶水，确保固定牢固。

胶水涂抹 - 黄色核心

#### 1.1.4 中轴

- **圆形杆:** 在中轴圆形杆和其他连接部件的接触点涂抹胶水。
- **顶端垫片和扭簧长端固定:** 在顶端垫片和扭簧长端接触的地方涂抹胶水，确保连接稳固。

胶水涂抹 - 中轴

### 1.2 组装步骤

1. **选择合适的胶水:** 使用适用于塑料或3D打印部件的强力胶水。
2. **涂抹胶水:** 按照上述图片中标记的部位均匀涂抹胶水。
3. **组装部件:** 快速对齐并压紧胶水涂抹的部件，确保每个部件紧密结合，没有间隙。
4. **等待胶水固化:** 按照胶水包装上的说明，等待胶水固化，确保粘合牢固。

### 1.3 注意事项

- 确保不要涂抹过多的胶水，以免溢出，影响外观或导致粘合不牢。
- 使用快速固化胶水以缩短等待时间，提高组装效率。
- 确保所有部件完全冷却后再进行组装，以确保胶水充分固化。
- 始终在通风良好的区域工作，避免吸入胶水的气味。
- 使用防护手套，避免与胶水直接接触，防止过敏或皮肤刺激。
- 使用保护垫或废纸，防止胶水溢出弄脏工作表面或其他部件。

## 2. 润滑脂涂抹位置

适当的润滑有助于确保各部件的顺畅运作，减少摩擦和磨损。请参考以下部分了解润滑脂应该涂抹到哪些部位：

- 在核心和中轴的接触部位涂抹润滑脂，以确保扭簧运作时的平滑性。
- 在中轴与外壳接触的两个圆饼上涂抹适量润滑脂，减少摩擦力。

*图中蓝色的部分是需要涂抹润滑脂的位置。*

### 2.1 中轴

以下图示展示了在中轴部分需要涂抹润滑脂的位置，请均匀涂抹润滑脂，减少摩擦并确保平稳旋转：

润滑脂涂抹 - 中轴

## 3. 扭簧模具使用

制作合适形状的扭簧可以借助扭簧弯曲模具。以下是使用扭簧弯曲模具的步骤：

1. 仓库中提供了弯曲模板的 [3mf 文件](../3mf/torsion-spring-bending-template.3mf)，根据扭簧方向选择对应的盘进行打印。
2. 准备好需要弯曲的扭簧，将扭簧放入模具的指定槽位。
3. 使用适当工具施加力量，使铁丝弯曲超过90度。
4. 剪断多余的铁丝。
5. 继续施加力量，使铁丝弯曲接近180度。
6. 从模具上取下扭簧，用钳子调整扭簧形状。

扭簧弯曲步骤

## 4. 回转轴安装

### 4.1 拓竹风格版本

如果采用分件打印，假设打印件进行分件打印的部分已经用胶水组合完毕。

#### 4.1.1 准备好的打印件

所有打印件

图片中的标号：

1. 外壳
2. 中轴
3. 绿色核心（根据需求选择绿色或黄色）
4. 轴盖
5. 底座
6. 垫片（默认1.2mm厚度，提供不同厚度）
7. 主爪爪座（*3）
8. 主爪带副爪安装槽位（*3）
9. 副主爪座（0 / *3）
10. 副爪（0 / *3）

副爪为可选的，所以数量为0或3。

#### 4.1.2 准备好五金件

1. 弯曲好的扭簧
2. 三波峰垫片 M27*34mm

五金件

#### 4.1.3 安装步骤

1. 按照正确的顺序和方向组装爪座和爪。
   1. 主爪座有个内部小突起，注意安装方向，将主爪推入爪座中，预留的余量应该可以使爪在爪座中固定好，如果有松动，模型上预留了m1.6规格的螺丝孔，可以使用m1.6*5沉头螺丝固定。

      如何组合主爪

   2. 副爪按图中平着推入后向下拉。

      如何组合副爪

2. 将绿色/黄色核心放入中轴（对应位置涂抹润滑脂）。
3. 固定扭簧（以绿色为例）：

   如何固定扭簧

4. 安装轴盖，对准槽位，按下轴盖后向右旋转轴盖。

   如何旋紧轴盖

5. 将中轴装入外壳（对应位置涂抹润滑脂）。
6. 底座放入垫片，放入三波峰垫圈。

   垫圈与底座

7. 将外壳底部凹槽与底座突起处对齐，按下外壳后向右旋转外壳。

   如何旋紧外壳与底座

8. 将主爪安装在外壳对应大槽位上。

   如何将主爪安装在外壳上

9. 将副爪安装在外壳对应小槽位上（可选）。

   如何将副爪安装在外壳上

### 4.2 通用版本

如果采用分件打印，假设打印件进行分件打印的部分已经用胶水组合完毕。

#### 4.2.1 准备好的打印件

所有打印件

图片中的标号：

1. 外壳
2. 外壳的支撑（需移除）
3. 轴盖
4. 底座
5. 垫片（默认1.2mm厚度，提供不同厚度）
6. 绿色核心（根据需求选择绿色或黄色）
7. 中轴
8. 料盘锁定螺母（高度8mm，最大外径80mm）

#### 4.2.2 准备好五金件

1. 弯曲好的扭簧
2. 三波峰垫片 M25*31mm

五金件

#### 4.2.3 安装步骤

1. 将绿色/黄色核心放入中轴（对应位置涂抹润滑脂）。
2. 固定扭簧（以绿色为例）：

   如何固定扭簧

3. 安装轴盖，对准槽位，按下轴盖后向右旋转轴盖。

   如何旋紧轴盖

4. 将中轴装入外壳（对应位置涂抹润滑脂）。
5. 底座放入垫片，放入三波峰垫圈。

   垫圈与底座

6. 将外壳底部凹槽与底座突起处对齐，按下外壳后向右旋转外壳。

   如何旋紧外壳与底座

7. 将一枚料盘螺母旋转到外壳上，后续装入料盘后再装入另一枚料盘螺母，注意锥度方向，装入料盘后记得锁紧。

   如何将主爪安装在外壳上

## 反馈与问题报告

如果在使用过程中遇到任何问题，或者对模型的使用有疑问，欢迎在本项目提 [Issue](https://github.com/zjoycelee/amslite-rotary-spool/issues) 进行反馈。

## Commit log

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2024-12-27 chore: folder structure finetuning
    [basic.stl, claw_seat_base.stl, claw_seat_clip.stl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]
2024-12-29 feat: add M1.6*5(Cross recessed countersunk head screw ) for claw_seat and claw
    note:
    name end with "with1.6Hole" means there is one hole on the model
    name end with "with1.6Holes" means there are 3 holes on the model
    [basicWithM1.6Hole.stl, basicWithM1.6Holes.stl, claw_seat_base-withM1.6Hole.stl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]
2024-12-30 fix: adjust clip size, remove claw component with single hole
    [claw_seat_base-withM1.6Hole.stl, claw_seat_base-withM1.6Holes.stl, claw_seat_clip.stl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]
2025-01-05 fix: adjust the tolerance of claw asd claw seat
    [claw_seat_base-withM1.6Holes.stl, claw_seat_complete-withM1.6Holes.stl]
2025-01-05 feat: add secondary claws and claw seats
    [basic_with_secondary_slots.stl, secondary_claw.stl, secondary_claw_seat.stl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]
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2025-01-06 feat: add a beam for secondary claw seat
    1. add a 0.8mm beam for secondary claw seat
    2. adjust the size of secondary claw seat slots on the shell
    3. add 0.6mm gasket on the shell top part
    [secondary_claw_seat.stl, shell_with_secondary-claws(thickened).stl]
2025-01-06 feat: make secondary claw longer, similar with main claw
    [secondary_claw.stl, secondary_claw_seat.stl]
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2025-01-07 refactor: finetuning folder structure, rename some models
    1. add the whole model
    1.1 shaft
    1.2 yellow_version
    1.3 green_version
    2. create new folder for xx_pieces
    3. rename models, eg. remove xxx_withM1.6Holes, for claw seat, named with main/secondary
    [base-part.stl, basic.stl, basicWithM1.6Hole.stl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]
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2025-01-08 refactor: remove unused file
    [claw_seat_base.stl]
2025-01-08 feat: update 3mf files
    1. all-in-one, all needed models in one plate
    2. amslite-rotary-spool-with-secondary-claws: divide into 3 plates
    first: include main claw seats, main claws, base, shell
    second: include core(both green and yellow), shaft, cover, 1.2mm gasket
    third: include secondary claw seats and secondary claws
    [all-in-one.3mf, amslite-rotary-spool-with-secondary-claws.3mf]
2025-01-12 feat: add 3mf file for pressure gaskets (include all ten thickness)
    [gaskets.3mf]
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2025-01-14 docs: finish user guide
    [torsion-spring-bending-template.3mf]
2025-01-14 fix: add missing clips for yellow core, adjust the shaft-limit in shell model.
    [shell(thickened).stl, yellow_version.stl]
2025-01-14 feat: add a new 3mf file include scattered models.
    - plate 1: All sizes of gaskets
    - plate 2: Torsion spring bending template (left and right versions included)
    - plate 3: Integrated main claw seat
    - plate 4: Integrated core (both yellow and green versions included)
    - plate 5: Integrated shaft
    [others.3mf]
2025-01-19 feat: add holder for amslite-rotary-spool, the connect part has slots for core clips
    1. add a length=160mm, d=18mm round rod, one end for green core, the other for yellow-core
    1.1 provide integration model
    1.2 provide a separate model, a shared round rod, a green part, a yellow part, screw on clockwise
    2. add the holder adapt ams riser v2
    [D18_L160mm(with-core-clip-slots).stl, D18_L160mm_shared_round_rod(with-core-clip-slots).stl, ams-riser-v2-ams-lite-rotary-holder-withAMS.3mf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]
2025-01-19 fix: make the shaft cover tighter, default offset 0.2mm than original one
    [all-in-one.3mf, amslite-rotary-spool-with-secondary-claws.3mf, shaft_cover.stl]
2025-01-23 feat: add a base, adapt three wave gasket size: M25*31, the dim of base is 80mm
    [base_d80.stl]
2025-01-23 feat: add shaft pieces, reduce the dim of cyclinder
    [bottom_disc_contact_waveform_gasket.stl, round_shaft_part.stl, top_disc_contact_core.stl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]
2025-01-23 feat: add shaft cover, this file is same with the bambu style one
    [shaft-cover.stl]
2025-01-24 feat: add shaft cover with number "1", "2", "3", "4"
    [amslite-spool-holderl-cap-with-number.3mf, cap_with_number1.stl, cap_with_number2.stl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]
2025-01-24 feat: add shell(with thread), and nut
    [nut.stl]
2025-01-24 refactor: remove common model
    [shaft-cover.stl]
2025-01-26 fix: resize base, remake a smoother nut
    [base_d60.stl, base_d80.stl, nut.stl]
2025-01-26 feat: add pressure adjust gaskets, total 10 size, thickness from 0.2-2mm
    [0.2mm.stl, 0.4mm.stl, 0.6mm.stl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]
2025-01-26 feat: add 3mf file for universal rotary spool holder
    [universal-amslit-rotary-spool-holder-with-auto-rewind.3mf]
2025-01-26 feat: make the concave bigger, add double threads
    [nut.stl, universal-amslit-rotary-spool-holder-with-auto-rewind.3mf, universal-amslite-rotary-spool-holder-with-auto-rewind.3mf]
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2025-01-28 feat: make the universal rotary spool holder smaller, update with latest stls
    [amslite-spool-holderl-cap-with-number.3mf]
2025-01-28 feat: add shaft in one object for the universal model
    [shaft.stl]
2025-01-28 feat: add "others" 3mf for universal version
    plate1: gaskets, from 0.2mm to 2mm, total 10 specifications
    plate2: torsion spring bending template, include left and right
    plate3: core, print with support, no glue needed, include green and yellow
    plate4: shaft, print with support, no glue needed
    [universal-others.3mf]
2025-01-29 fix: correct typo
    [amslite-spool-holder-cap-with-number.3mf]
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2025-01-30 docs: correct universal version total print time and filament usage
2025-02-21 feat: add hollowed shaft cover for core rotation visibility during debugging
    - Updated the lid design to include a hollow center, allowing users to observe the internal core's rotation.
    - Enhances debugging and user experience by providing a visual reference of the core in action.
    [shaft_cover_hollowed.stl]
2025-03-08 docs: add debug guide and provide 3mf files
    [debug-bambu-style.3mf, debug-universal.3mf]
2025-03-08 fix: replace 1.4 with 1.6
    [debug-bambu-style.3mf, debug-universal.3mf]
2025-03-16 fix: adjust the interior diameter of shaft.
    [[fix-file]shaft-adapter.stl, all-in-one.3mf, amslite-rotary-spool-with-secondary-claws.3mf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]
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
